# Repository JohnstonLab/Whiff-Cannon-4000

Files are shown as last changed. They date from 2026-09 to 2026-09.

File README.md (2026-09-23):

# Whiff Cannon 4000
Odor Gun tribute

♫ This is not the greatest olfactometer in the world, no. This is just a tribute ♫ [to [Burton et al, 2019](https://pubmed.ncbi.nlm.nih.gov/30657873)]. [#Tribute](https://www.youtube.com/watch?v=_lK4cX5xGiQ)
We were inspired to build this after Matt Wachowiak’s presentation at ECRO 2025. 

The logic of the olfactometer’s operation is detailed in [the original paper](https://pubmed.ncbi.nlm.nih.gov/30657873).  
This page details the following:
1) Our [Modifications](#Modifications)
2) The 3D print files for our [custom parts](#custom-parts) 
3) Off the shelf [parts list](#off-the-shelf-parts-list)
4) Jupyter notebook based **[software](#Software) to control the olfactometer**, including outputting the timing and valve that was actuated, triggering of other devices and recording of signals (e.g. PID alongside valve timings)
5) [Calibration data](#Calibrations) for our assembled device

The building and testing of this olfactometer were carried out primarily by Georgina Bonny, Adam Barrett and Shreya Choudhuri.

If you use any of this project please cite:  and [the original paper](https://pubmed.ncbi.nlm.nih.gov/30657873).

## Modifications
We have made the following adjustments:

1) Decreased diameter of carrier stream (13.87 mm inner diameter reduced to 5 mm).
2) Increased capacity of odour reservoirs (we were unable to source the original reservoirs in Europe). 

Our delivery barrel was redesigned to account for these differences as shown below.
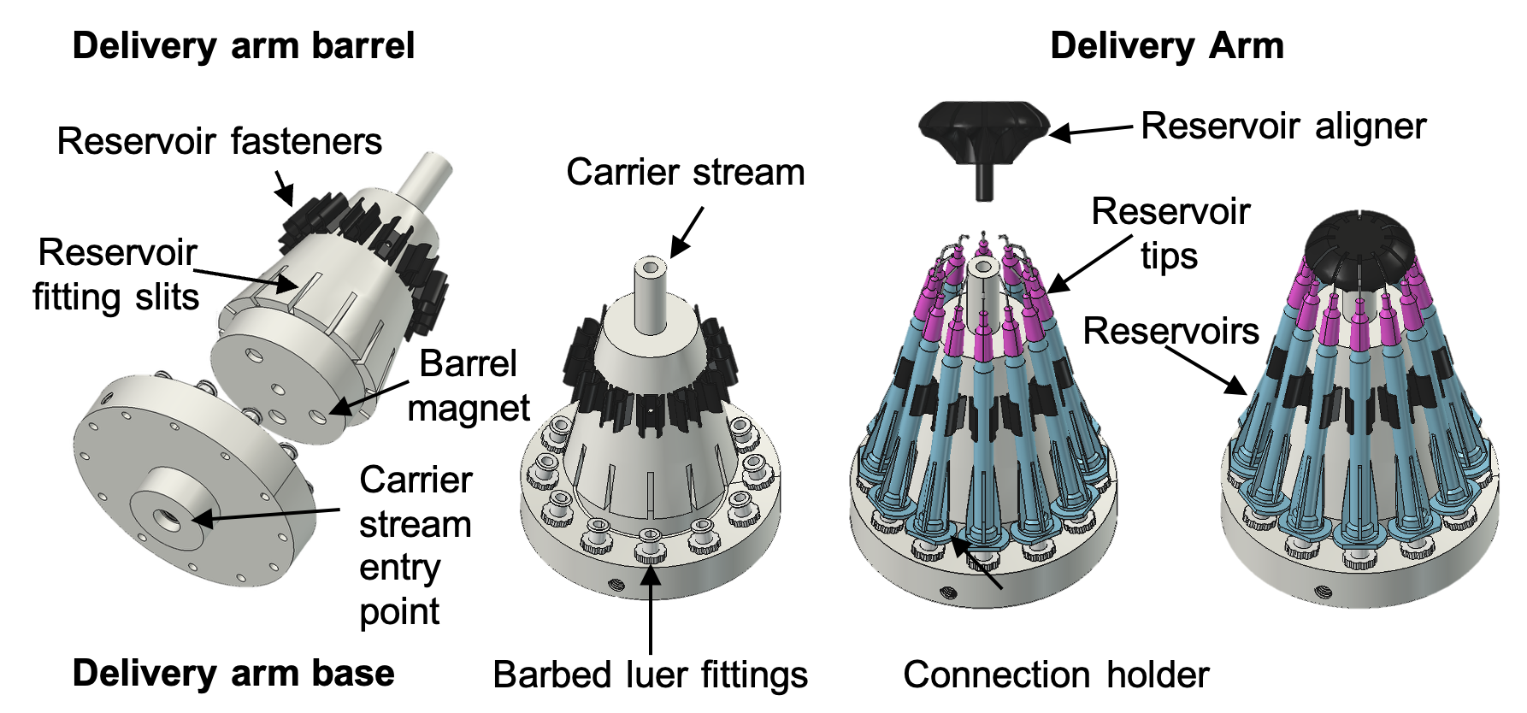
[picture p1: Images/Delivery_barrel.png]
Delivery barrel assembly

Delivery assembly IRL    
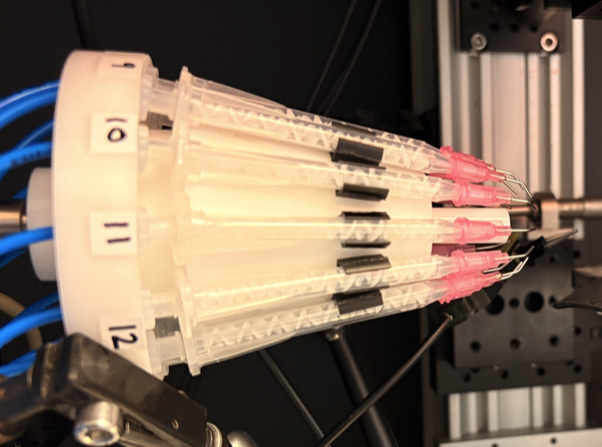
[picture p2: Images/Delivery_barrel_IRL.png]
Delivery barrel assembly IRL


The top mount can be easily and rapidly switched, enabling many 10s to over 100 odours to be delivered to a single animal. 

The enclosure housing the solenoid valves and electronics was made from a Thorlabs enclosure.	

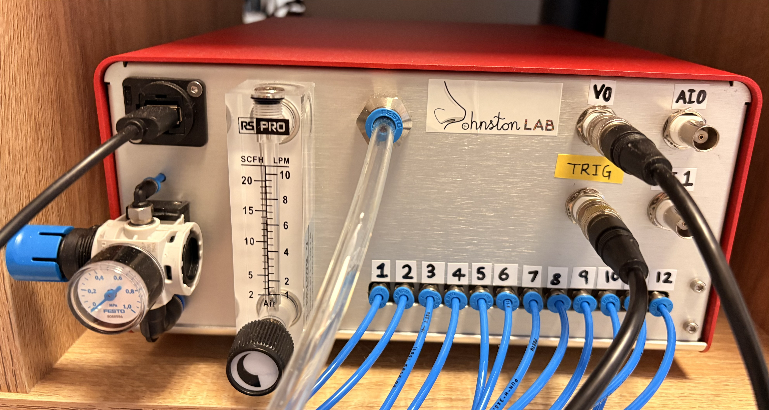
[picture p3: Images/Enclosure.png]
Enclosure

- There are 2 analog inputs (AI0 & AI1) enabling recording of PID and valve actuations
- VO gives a signal corresponding to valve and carrier stream activity
- Trig provides an output TTL for triggering other equipment

## Custom parts
[We provide 3D print files for the delivery barrel and tip aligner](https://github.com/JohnstonLab/Whiff-Cannon-4000/tree/main/Custom_parts). The tip aligner ensures the tips are aligned into the narrower carrier stream.

## Off the shelf parts list
[Parts list](off_the_shelf_components.md) for all other components and consumables that may be easier to source for interested Europeans.

## Software
The software is based on our Better Olfactometer Software(s) [BOSs repository](https://github.com/JohnstonLab/BOSs).
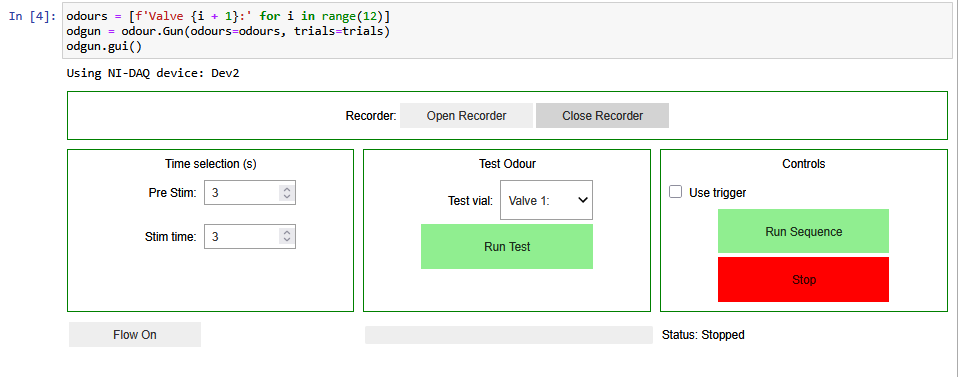
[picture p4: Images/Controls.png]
Controls

- Time setting box applies only to running a test. You can select a valve from the drop down menu and deliver a single trial by clicking 'Run Test'. 
- 'Flow on' button turns carrier stream on and sets the VO BNC port to 0.5V to indicate that flow is on
- 'Stop' button closes all valves and stops the carrier stream, can interrupt all other processes.
- 'Use trigger' checkbox will generate a TTL pulse at the start of each 'Pre (s)' period defined in a protocol sequence
- 'Run Sequence' will execute a sequence that has been loaded in the previous cell. Sequences are stored as csv files with the following structure. You can create multiple sequences and load them as necessary. The progress bar indicates place in sequence and the 'Status:' text will report the next step of the sequence.

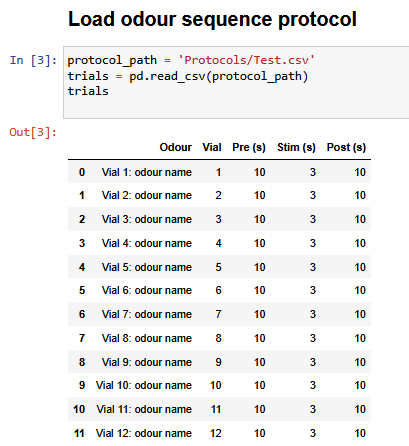
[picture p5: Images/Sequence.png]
Sequence example

- Open / close Recorder, opens a new floating window to display and record signals from AI0 & AI1. It can be used simultaneously with the control panel in the Jupyter notebook.
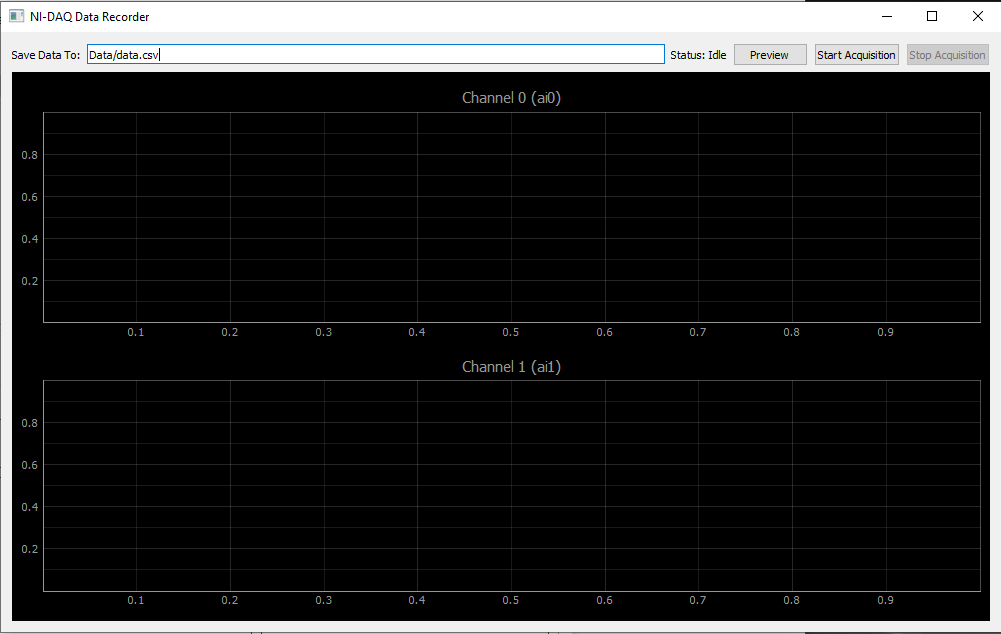
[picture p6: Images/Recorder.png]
Recorder


## Calibrations
We routinely use 0.2 MPa for the odour delivery valve pressure and 3 l min -1 for the flow rate of the carrier stream, with the whiff canon 4000 positioned 4 cm from the nose of the subject.

### Odour pressure 
Varying the odour delivery valve pressure, all measured with the carrier stream set at 3 l min-1. Measured with a miniPID 4 mm from whiff cannon 4000 tip.
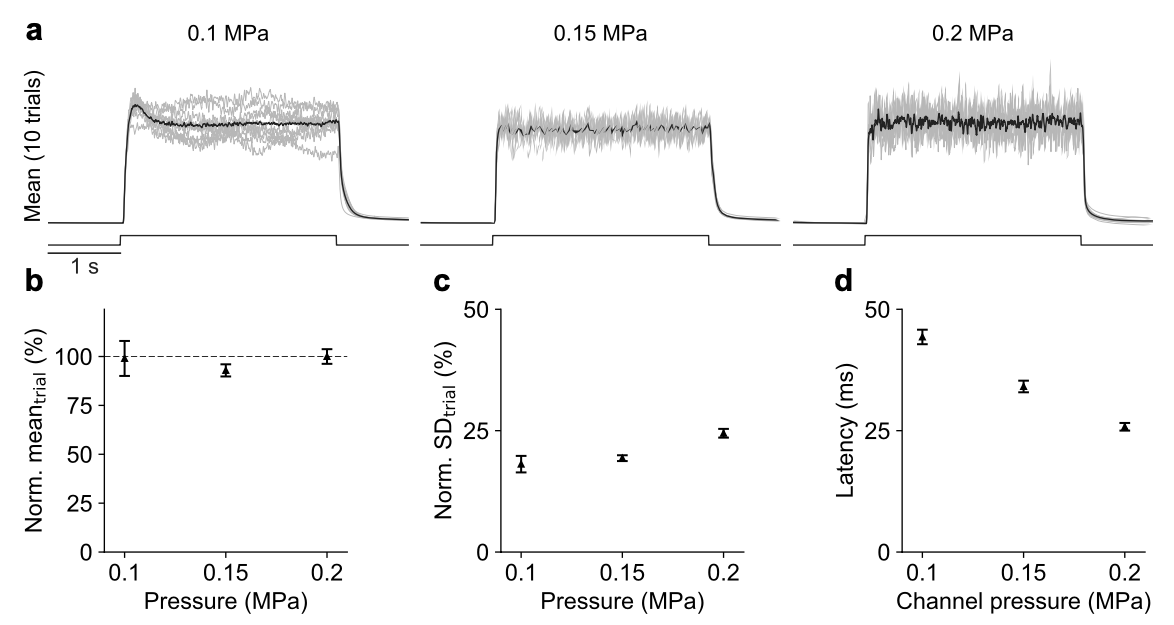
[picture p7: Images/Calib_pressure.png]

### Carrier flow
Varying flow rate of carrier stream with valve pressure held at 0.2 MPa. Measured with a miniPID 4 mm from whiff cannon 4000 tip.
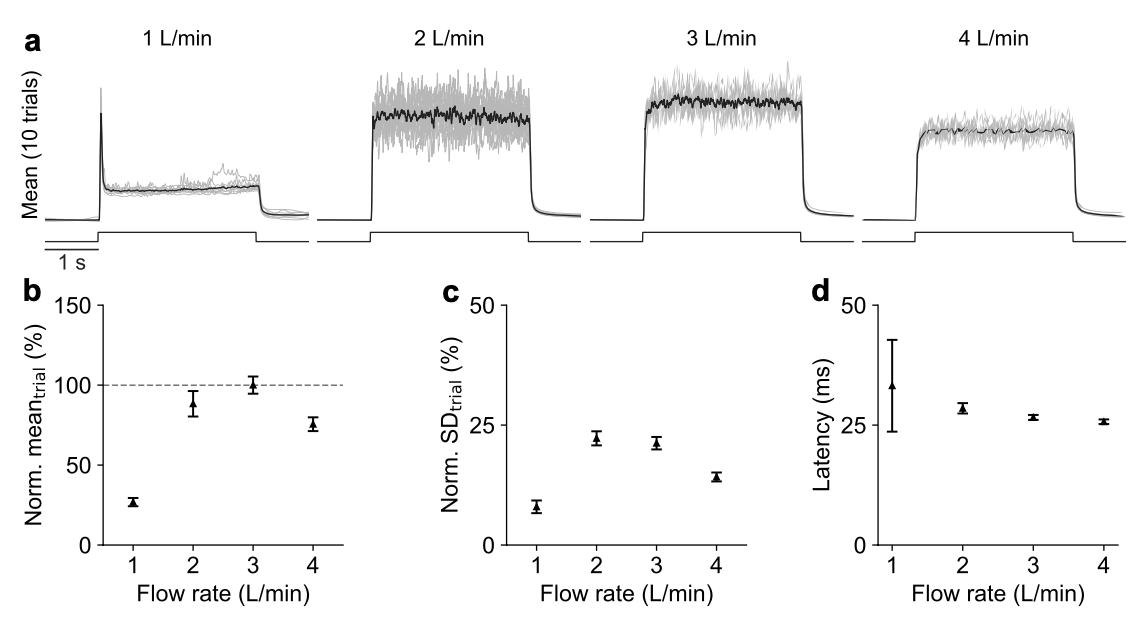
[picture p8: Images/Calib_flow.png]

### Distance 
Varying distance between whiff canon 4000 tip and test subject.
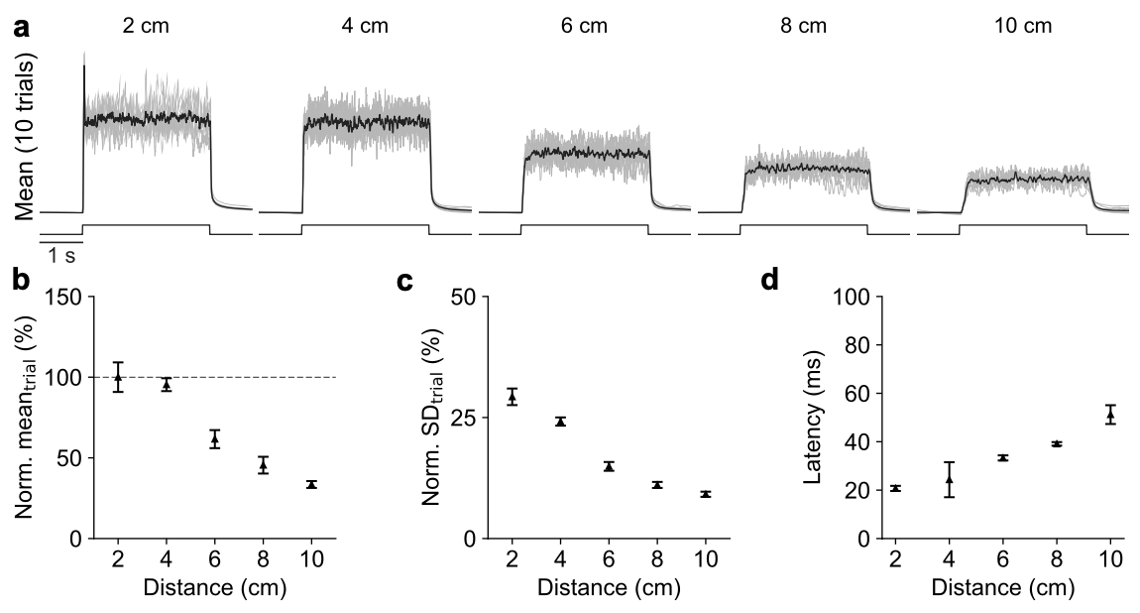
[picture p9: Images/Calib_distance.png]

### Multiple valves 
Single trial plume visualisation using TiCl4, red box indicates distance of test subject.
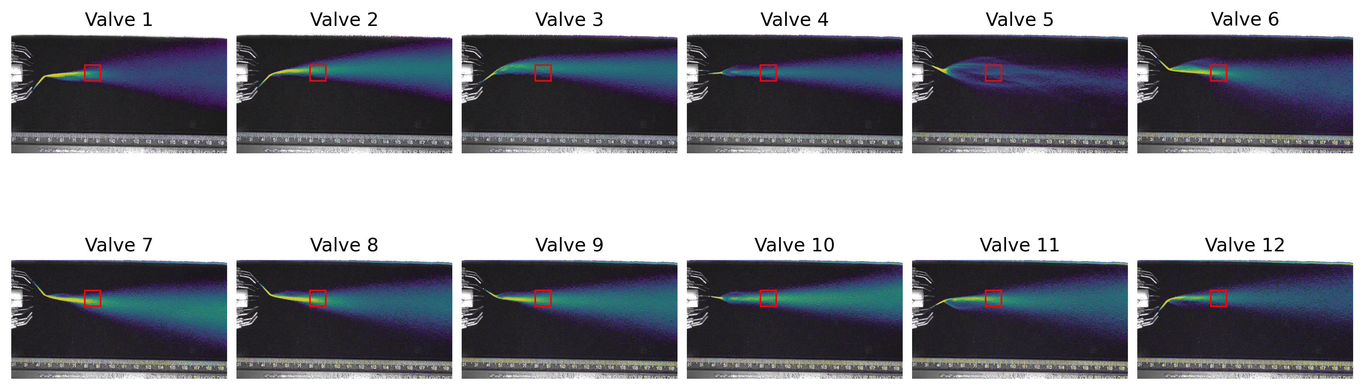
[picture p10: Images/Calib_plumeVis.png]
Plume visualisation

Mean PID recordings for each channel.
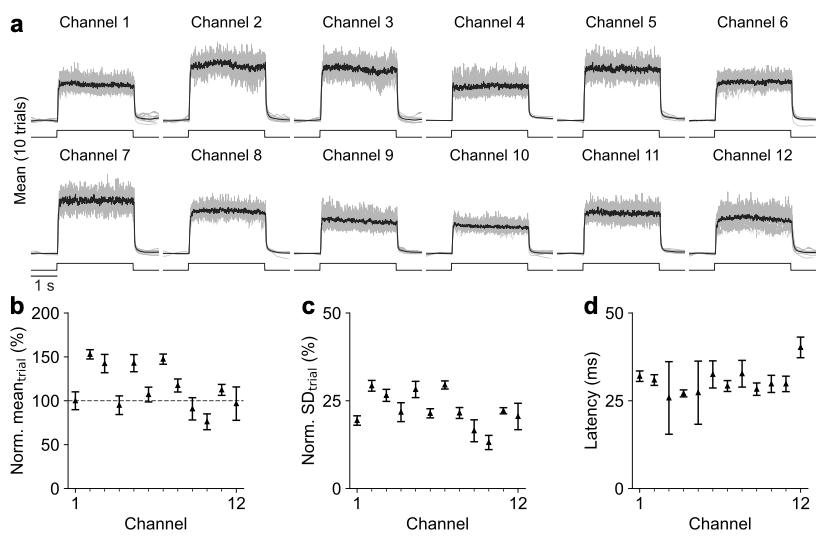
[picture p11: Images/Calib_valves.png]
PID for all channels


## Etymology
Whiff cannon 4000, why 4000? The number of preceding prototypes? Its firing position in decamicrons from the nose? Or maybe it's just there for a bit of bombastic bathos.

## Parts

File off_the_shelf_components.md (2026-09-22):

# Off-the-Shelf Components

| Olfactometer component | Part | Supplier (cat. #) |
|---|---|---|
| Flow control housing | Air flow sensor | RS Pro (257-6412) |
| | Barbed connector | SMC (M-5AN-4) |
| | Channel driver array | Microchip (MIC2981/82YN) |
| | Circuit board | Multicomp Pro (MC01009) |
| | DAQ Device | NI (USB-6001) |
| | Enclosure | Thorlabs (EC2530CR) |
| | Manifold | SMC (VV100-S41-12-M5) |
| | Pressure regulator | Festo (MS2-LR-M5-D6-AR-MPA-B) |
| | Solenoid valve | SMC (VX213AGAXB) |
| | Solenoid valve driver | SMC (V114-5LOU) |
| | 24 V power supply | RS Pro (201-2631) |
| | Tee-Connector 6mm | SMC (KQ2T06-00) |
| | Terminal Ground Bar | Sourcing map (s25050901ux2098) |
| | DIN valve connector | SMC (SY100-30-4A) |
| | BNC | Amphenol RF (B6251G2-NPP3G-50) |
| | USB A to USB A cable | RS Pro (182-8482) |
| | Chassis Mount Barrel Jack | MCM (27-4360) |
| | USB A to Micro USB B cable | RS Pro (304-18-252) |
| | Straight push in pneumatic fitting (2mm) | Festo (QSM-M5-3) |
| | Straight push in pneumatic fitting (6mm) | SMC (KQB2H06-G01) |
| | Push in bulkhead fitting (8mm) | Farnell (3431832) |
| | 6mm elbow push fitting | RS Pro (144-2613) |
| | 6mm Male push fitting | Festo (QSM-M6-6) |
| Connections | 2 mm Tubing | Festo (PEN-2X1-BL) |
| | 6 mm Tubing | Festo (PEN-6X1-BL) |
| | 8 mm Carrier flow tubing | RS Pro (917-2404) |
| Delivery arm and barrel | Aligner | Custom-machined |
| | Base | Custom-machined |
| | Eductor | Custom-machined |
| | Odorant reservoir fastener | Custom-machined |
| | Luer Fittings | Fischer Scientific (11745818) |
| Disposables | Reservoirs | Rockingham systems (100816) Static mixer RMX-5-16N |
| | 45º Bend Reservoir tips | ADL (AD72005045) |

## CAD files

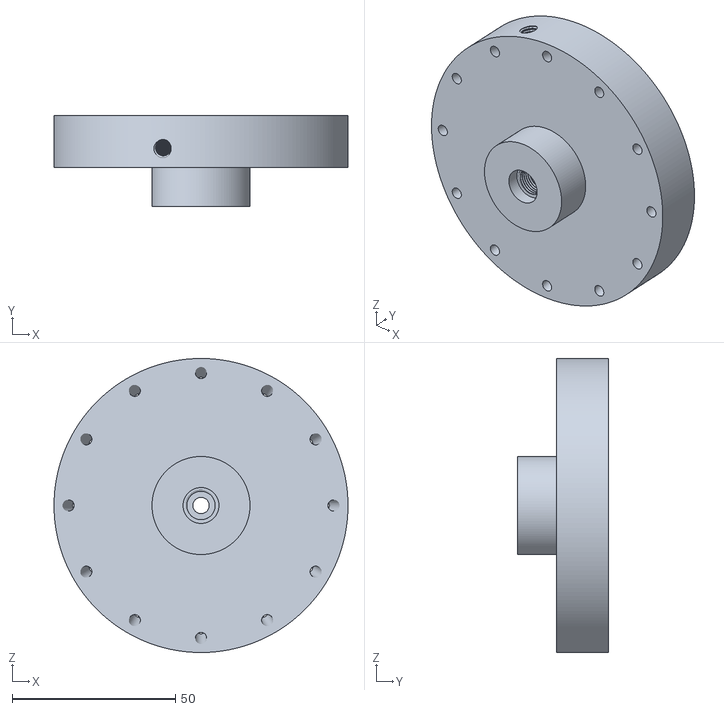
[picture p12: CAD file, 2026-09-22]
Custom_parts/Base Mount Body.stl
90.0 x 27.8 x 90.0

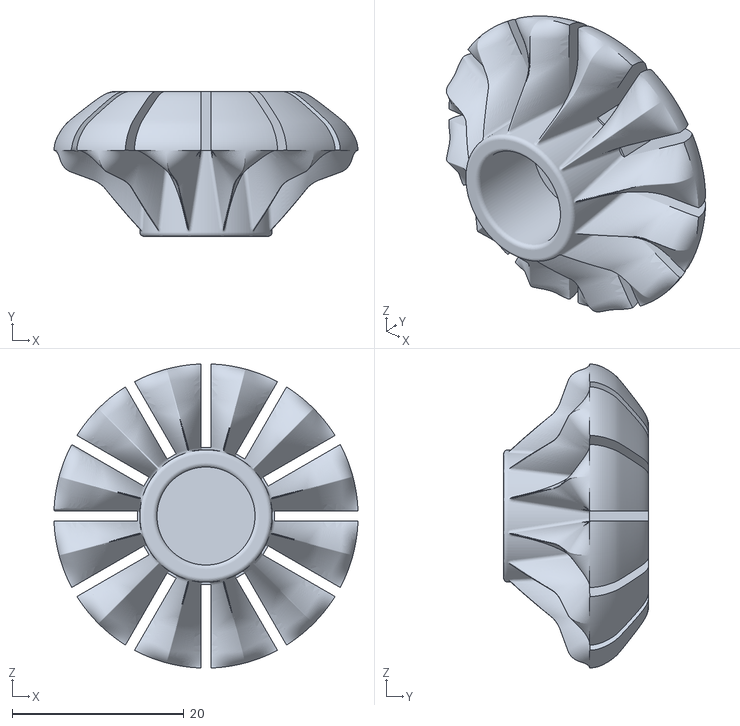
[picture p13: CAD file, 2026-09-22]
Custom_parts/Aligner V3_1.stl
35.4 x 16.9 x 35.4

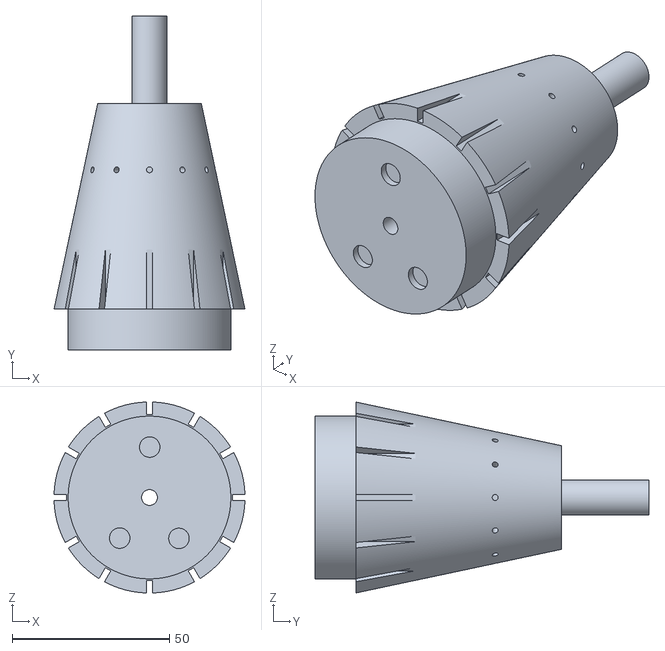
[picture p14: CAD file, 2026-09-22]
Custom_parts/Top Mount 2_0.stl
60.6 x 106.1 x 60.6

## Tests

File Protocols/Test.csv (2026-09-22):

Odour | Vial | Pre (s) | Stim (s) | Post (s)
Vial 1: odour name | 1 | 10 | 3 | 10
Vial 2: odour name | 2 | 10 | 3 | 10
Vial 3: odour name | 3 | 10 | 3 | 10
Vial 4: odour name | 4 | 10 | 3 | 10
Vial 5: odour name | 5 | 10 | 3 | 10
Vial 6: odour name | 6 | 10 | 3 | 10
Vial 7: odour name | 7 | 10 | 3 | 10
Vial 8: odour name | 8 | 10 | 3 | 10
Vial 9: odour name | 9 | 10 | 3 | 10
Vial 10: odour name | 10 | 10 | 3 | 10
Vial 11: odour name | 11 | 10 | 3 | 10
Vial 12: odour name | 12 | 10 | 3 | 10

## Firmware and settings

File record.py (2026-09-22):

# odour.py
'''
Writen by Johnston lab 2025
Designed to work with a NIDAQ-6001
Records 2 channels of analog in data at 1kHz with live display
'''
import sys, time, csv, threading
import numpy as np
import nidaqmx
from nidaqmx.constants import AcquisitionType, TerminalConfiguration # MODIFIED: Added TerminalConfiguration
from nidaqmx.system import System
from PyQt5 import QtWidgets, QtCore
import pyqtgraph as pg
import os 
import re 


class Record(QtWidgets.QWidget): # CHANGED: Class name changed from SmoothDAQViewer to Record
    acquisition_state_changed = QtCore.pyqtSignal(bool)
    acquisition_error = QtCore.pyqtSignal(str)

    """
    Continuous NI-DAQ data viewer using a ring buffer for smooth plotting and
    a separate thread for full-rate data acquisition and logging.
    """
    def __init__(self, sample_rate=1000, samples_per_read=100, window_sec=5, filename="Data/data.csv"):
        super().__init__()
        self.setWindowTitle("NI-DAQ Data Recorder") # CHANGED: Updated window title

        # --- Configuration and State ---
        self.fs = sample_rate          # Sampling rate (Hz)
        self.read_n = samples_per_read # Samples acquired per read call
        self.win_sec = window_sec      # Time window to display on plot (seconds)
        self.running = False           # Flag for acquisition thread state
        self.save_data = False         # True when actively recording to CSV
        self.reader = None             # Acquisition thread handle
        self._buffer_lock = threading.Lock()

        # --- NI-DAQ Setup ---
        # Detect the first available device (e.g., 'Dev1')
        try:
            self.dev = System.local().devices[0].name
        except IndexError:
             raise RuntimeError("No NI-DAQ device found.")
        print(f"Using NI-DAQ device: {self.dev}")

        self.task = nidaqmx.Task()
        # Add two analog input channels (ai0 and ai1)
        # MODIFIED: Added terminal_config=TerminalConfiguration.RSE to both channels
        self.task.ai_channels.add_ai_voltage_chan(
            f"{self.dev}/ai0", 
            max_val=10.0, 
            min_val=-10.0,
            terminal_config=TerminalConfiguration.RSE
        )
        self.task.ai_channels.add_ai_voltage_chan(
            f"{self.dev}/ai1", 
            max_val=10.0, 
            min_val=-10.0,
            terminal_config=TerminalConfiguration.RSE
        )

        # Configure continuous sampling timing
        self.task.timing.cfg_samp_clk_timing(
            self.fs,
            sample_mode=AcquisitionType.CONTINUOUS,
            samps_per_chan=self.read_n
        )

        # --- Ring Buffer Initialization ---
        # The buffer holds 2x the display window size for safe wrap-around handling
        self.buflen = int(self.fs * self.win_sec * 2)
        # 2 channels (rows), buffer length (columns)
        self.data = np.zeros((2, self.buflen))
        self.time = np.zeros(self.buflen)
        self.ptr = 0 # Current total samples acquired (index pointer)

        # --- UI Setup (Vertical Layout) ---
        main_layout = QtWidgets.QVBoxLayout(self)

        # Control layout (Horizontal)
        ctrl_layout = QtWidgets.QHBoxLayout()
        self.file_edit = QtWidgets.QLineEdit(filename)
        self.status_label = QtWidgets.QLabel("Status: Idle")
        self.preview_btn = QtWidgets.QPushButton("Preview")
        self.start_btn = QtWidgets.QPushButton("Start Acquisition")
        self.stop_btn = QtWidgets.QPushButton("Stop Acquisition")
        self.stop_btn.setEnabled(False)

        ctrl_layout.addWidget(QtWidgets.QLabel("Save Data To:"))
        ctrl_layout.addWidget(self.file_edit)
        ctrl_layout.addWidget(self.status_label)
        ctrl_layout.addWidget(self.preview_btn)
        ctrl_layout.addWidget(self.start_btn)
        ctrl_layout.addWidget(self.stop_btn)
        main_layout.addLayout(ctrl_layout)

        # Plot Widget
        self.plot_widget = pg.GraphicsLayoutWidget()
        main_layout.addWidget(self.plot_widget)

        # Plot 1 (Channel 0) - Top Plot
        self.p1 = self.plot_widget.addPlot(title="Channel 0 (ai0)")
        self.p1.showGrid(x=True, y=True)
        self.c1 = self.p1.plot(pen='y')

        # Move to the next row for vertical stacking (Crucial for vertical arrangement)
        self.plot_widget.nextRow()

        # Plot 2 (Channel 1) - Bottom Plot
        self.p2 = self.plot_widget.addPlot(title="Channel 1 (ai1)")
        self.p2.showGrid(x=True, y=True)
        self.c2 = self.p2.plot(pen='c')

        # --- Connections and Timer ---
        self.preview_btn.clicked.connect(self.preview)
        self.start_btn.clicked.connect(self.start)
        self.stop_btn.clicked.connect(self.stop)
        self.acquisition_state_changed.connect(self._on_acquisition_state_changed)
        self.acquisition_error.connect(self._on_acquisition_error)

        # Timer to periodically update the plot (GUI refresh rate, e.g., 20 FPS)
        self.timer = QtCore.QTimer()
        self.timer.timeout.connect(self.update_plot)
        self.timer.start(50)
        
    def _find_next_filename(self, base_filename):
        """
        Finds the next available filename by appending a zero-padded index (e.g., _000, _001, _010).
        It first strips any existing index from the filename to ensure correct sequential numbering.
        """
        # Split filename into root and extension (e.g., 'data' and '.csv')
        root, ext = os.path.splitext(base_filename)
        
        # FIX: Strip any existing _XXX index from the root name (e.g., 'data_001' -> 'data')
        # This ensures the numbering always starts from the clean base name.
        root = re.sub(r'_\d{3}$', '', root)
        
        # MODIFIED: Start the index search from 0 (for data_000.csv)
        index = 0
        while index < 1000: # Limit check to prevent indefinite loop
            # Use f-string formatting to zero-pad the index to three digits
            new_filename = f"{root}_{index:03d}{ext}"
            if not os.path.exists(new_filename):
                return new_filename
            index += 1
            
        # Fallback if 1000 indexed files already exist
        return base_filename 

    # --- Acquisition Thread Logic ---
    def acq_loop(self):
        """Runs in a separate thread to continuously read NI-DAQ data and optionally log to CSV."""
        writer_obj = None
        try:
            if self.save_data:
                # The filename is guaranteed to be unique thanks to start()
                writer_obj = open(self.file_edit.text(), "w", newline="")
                w = csv.writer(writer_obj)
                w.writerow(["Time(s)", "Ch0(V)", "Ch1(V)"])

            while self.running:
                # Read a block of samples (2 channels x self.read_n samples)
                block = np.array(self.task.read(number_of_samples_per_channel=self.read_n))

                # Reshape if only one channel was read (safety check, though 2 are configured)
                if block.ndim == 1:
                    block = block[np.newaxis, :]

                n = block.shape[1]
                # Calculate time array for the new block relative to the start of acquisition
                t = (np.arange(n) + self.ptr) / self.fs

                # --- Ring Buffer Write Logic (Wrap-around handling) ---
                with self._buffer_lock:
                    i0 = self.ptr % self.buflen # Start index in buffer
                    i1 = (i0 + n) % self.buflen # End index in buffer

                    if i1 > i0:
                        # Simple case: No wrap-around
                        self.data[:, i0:i1] = block
                        self.time[i0:i1] = t
                    else:
                        # Wrap-around case: Data splits into two segments
                        k = self.buflen - i0
                        # Segment 1: from i0 to end of buffer
                        self.data[:, i0:] = block[:, :k]
                        self.time[i0:] = t[:k]
                        # Segment 2: from start of buffer to i1
                        self.data[:, :i1] = block[:, k:]
                        self.time[:i1] = t[k:]

                    self.ptr += n # Advance the total sample pointer

                if self.save_data:
                    # Save full-rate data to CSV
                    # Using np.transpose to iterate rows efficiently
                    w.writerows(zip(t, *block))
        except Exception as e:
            print(f"Acquisition Error: {e}")
            self.acquisition_error.emit(str(e))
        finally:
            if writer_obj is not None:
                writer_obj.close()
            print("Acquisition thread ended.")
            # Ensure UI reflects stopped state if error occurred
            self.running = False
            self.save_data = False
            self.acquisition_state_changed.emit(False)

    def _start_acquisition(self, save_data):
        """Starts acquisition in either preview mode or recording mode."""
        if self.running or (self.reader is not None and self.reader.is_alive()):
            return

        self.save_data = save_data
        if self.save_data:
            # Determine the unique filename and update the QLineEdit display
            new_filename = self._find_next_filename(self.file_edit.text())
            self.file_edit.setText(new_filename)
            self.status_label.setText("Status: Recording")
            print(f"Acquisition started, saving to {self.file_edit.text()}")
        else:
            self.status_label.setText("Status: Preview")
            print("Preview started (display only, no file will be written).")

        self.running = True
        self.ptr = 0 # Reset buffer pointer on start
        self.acquisition_state_changed.emit(True)

        # Start the background data reader thread
        self.reader = threading.Thread(target=self.acq_loop, daemon=True)
        self.reader.start()

    def preview(self):
        """Starts a live preview without recording data to disk."""
        self._start_acquisition(save_data=False)

    def start(self):
        """Starts the NI-DAQ task and acquisition thread with CSV recording enabled."""
        self._start_acquisition(save_data=True)


    def stop(self):
        """Sets the flag to stop the acquisition thread."""
        if not self.running:
            return
        self.status_label.setText("Status: Stopping")
        self.running = False
        self.save_data = False
        self.stop_btn.setEnabled(False)
        # Note: The thread will finish its current read and exit the loop gracefully.


    def update_plot(self):
        """Updates the pyqtgraph plot with the latest data from the ring buffer."""
        if not self.running:
            return

        with self._buffer_lock:
            # Calculate the size of the data window to display
            nwin = int(self.fs * self.win_sec)
            end = self.ptr % self.buflen # Current end index in the buffer
            start = (end - nwin) % self.buflen # Start index for the display window

            # --- Ring Buffer Read Logic (Wrap-around handling) ---
            if start < end:
                # Simple case: Data is contiguous
                x = self.time[start:end].copy()
                y0 = self.data[0, start:end].copy()
                y1 = self.data[1, start:end].copy()
            else:
                # Wrap-around case: Concatenate the end and start segments
                x = np.concatenate((self.time[start:], self.time[:end]))
                y0 = np.concatenate((self.data[0, start:], self.data[0, :end]))
                y1 = np.concatenate((self.data[1, start:], self.data[1, :end]))

        # Decimate the data for faster plotting if there are too many points
        decim = max(1, len(x)//2000)
        x_decim = x[::decim]
        y0_decim = y0[::decim]
        y1_decim = y1[::decim]

        # Update plot data
        self.c1.setData(x_decim, y0_decim)
        self.c2.setData(x_decim, y1_decim)

        # Autoscroll the X-axis to show the latest window
        if x.size > 0:
            for p in (self.p1, self.p2):
                p.setXRange(x[-1] - self.win_sec, x[-1])

    @QtCore.pyqtSlot(bool)
    def _on_acquisition_state_changed(self, running):
        self.file_edit.setReadOnly(running)
        self.preview_btn.setEnabled(not running)
        self.start_btn.setEnabled(not running)
        self.stop_btn.setEnabled(running)
        if not running and not self.status_label.text().startswith("Status: Error"):
            self.status_label.setText("Status: Idle")

    @QtCore.pyqtSlot(str)
    def _on_acquisition_error(self, error_message):
        self.status_label.setText(f"Status: Error - {error_message}")
        QtWidgets.QMessageBox.critical(self, "Acquisition Error", error_message)


    def closeEvent(self, event):
        """
        Called when the application window is closed. Ensures the acquisition 
        thread is stopped and the NI-DAQ task is closed properly.
        """
        print("Application closing: Stopping DAQ task and thread...")
        self.stop()
        # Give the thread a moment to finish its current read and exit loop
        if self.reader is not None and self.reader.is_alive():
            self.reader.join()

        # Essential: Close the NI-DAQ task handle to release resources
        self.task.close()
        event.accept()


def main():
    """Main application entry point."""
    app = QtWidgets.QApplication(sys.argv)
    w = Record(sample_rate=1000, samples_per_read=100, window_sec=5) # CHANGED: Class instantiation
    w.resize(1000, 600)
    w.show()
    sys.exit(app.exec_())


if __name__ == "__main__":
    main()

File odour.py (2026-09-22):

# odour.py
'''
Writen by Johnston lab 2025
Designed to work with a NIDAQ-6001
Runs in jupyterlab
'''

import asyncio
import subprocess
import sys
from pathlib import Path
import numpy as np
import pandas as pd
import ipywidgets as widgets
import nidaqmx

class Gun:
    NUM_VALVES = 12
    REQUIRED_TRIAL_COLUMNS = ("Pre (s)", "Stim (s)", "Vial")
    TRIGGER_PULSE_S = 0.02

    def __init__(self, odours, trials=None):
        # -------------------------------
        # Save user data
        # -------------------------------
        self.odours = odours
        self.trials = trials
        self.running = False
        self.FLOW = 0
        self._run_task = None
        self._record_process = None
        self._record_script = Path(__file__).with_name("record.py")

        # -------------------------------
        # Detect NI-DAQ devices
        # -------------------------------
        devices = [device.name for device in nidaqmx.system.System.local().devices]
        if not devices:
            raise RuntimeError("No NI-DAQ devices detected. Please connect a device.")
        self.device_name = devices[0]
        print(f"Using NI-DAQ device: {self.device_name}")

        # -------------------------------
        # Setup digital output channels
        # -------------------------------
        self.gunValves = nidaqmx.Task()
        for i in range(8):
            self.gunValves.do_channels.add_do_chan(f"{self.device_name}/port0/line{i}")
        for i in range(4):
            self.gunValves.do_channels.add_do_chan(f"{self.device_name}/port1/line{i}")
        
        self.flowValve = nidaqmx.Task()
        self.flowValve.do_channels.add_do_chan(f"{self.device_name}/port2/line0")

        # -------------------------------
        # Setup analog output channel
        # -------------------------------
        self.gunAO = nidaqmx.Task()
        self.gunAO.ao_channels.add_ao_voltage_chan(f"{self.device_name}/ao0")

        self.triggerAO = nidaqmx.Task()
        self.triggerAO.ao_channels.add_ao_voltage_chan(f"{self.device_name}/ao1")
        self.triggerAO.write(0)

        # -------------------------------
        # GUI widgets
        # -------------------------------
        self.txSize = widgets.Layout(width='60%', height='45px')
        self.buttonSize = widgets.Layout(width='60%', height='50px')

        self.FlowOn = widgets.Button(description='Flow On')
        self.FlowOn.on_click(self.flowStart)

        self.Stopflow = widgets.Button(description='Stop', layout=self.buttonSize, style={'button_color':'red'})
        self.Stopflow.on_click(self.stop)

        self.StartRecord = widgets.Button(description='Open Recorder')
        self.StartRecord.on_click(self.start_recorder)
        self.StopRecord = widgets.Button(description='Close Recorder', style={'button_color':'lightgray'})
        self.StopRecord.on_click(self.stop_recorder)

        self.OdourList = widgets.Dropdown(options=self.odours, value=self.odours[0],
                                         description='Test vial:', disabled=False, layout=self.txSize)

        self.Run = widgets.Button(description='Run Sequence', style={'button_color':'lightgreen'}, layout=self.buttonSize)
        self.Run.on_click(self.running_seq)

        self.RunTest = widgets.Button(description='Run Test', style={'button_color':'lightgreen'}, layout=self.buttonSize)
        self.RunTest.on_click(self.running_test)

        self.StimDur = widgets.BoundedFloatText(value=3, min=0.02, max=120, description='Stim time:', layout=self.txSize)
        self.PreStim = widgets.BoundedFloatText(value=3, min=0, description='Pre Stim:', layout=self.txSize)
        self.UseTrigger = widgets.Checkbox(value=False, description='Use trigger', indent=False)

        self.prog = widgets.IntProgress(value=0, min=0, max=10, step=1, orientation='horizontal',
                                        layout=widgets.Layout(width='100%'))
        self.Status = widgets.Label(value='Status: Stopped', layout=widgets.Layout(width='100%', height='50px'))

    # -------------------------------
    # Valve control functions
    # -------------------------------
    def flow_on(self):
        d = np.ones(1)
        self.flowValve.write(d == 1)
        self.FLOW = 1
        self.gunAO.write(1)
        # print(f"Valve {v} ON, AO={(v + 1) / 2}")

    def _validate_vial_index(self, v):
        if not 0 <= int(v) < self.NUM_VALVES:
            raise ValueError(f"Valve index must be between 0 and {self.NUM_VALVES - 1}. Got: {v}")

    def _set_run_state(self, is_running):
        self.running = is_running
        self.Run.disabled = is_running
        self.RunTest.disabled = is_running

    def _validate_trials(self):
        if self.trials is None:
            raise ValueError("No trials loaded. Provide a trial DataFrame before running the sequence.")
        missing = [c for c in self.REQUIRED_TRIAL_COLUMNS if c not in self.trials.columns]
        if missing:
            raise ValueError(f"Trials missing required columns: {missing}")

        trial_df = self.trials.copy()
        if "Post (s)" not in trial_df.columns:
            trial_df["Post (s)"] = 0
            print("Protocol missing 'Post (s)' column; assuming 0 s post time.")

        for col in ("Pre (s)", "Stim (s)", "Post (s)", "Vial"):
            trial_df[col] = pd.to_numeric(trial_df[col], errors="raise")
        if (trial_df["Vial"] < 1).any() or (trial_df["Vial"] > self.NUM_VALVES).any():
            raise ValueError(f"'Vial' values must be in range 1-{self.NUM_VALVES}.")
        self.trials = trial_df

    def _start_task(self, coro, status):
        if self._run_task is not None and not self._run_task.done():
            self.Status.value = "Status: Already running. Stop current run before starting a new one."
            return

        self.Status.value = status
        self._set_run_state(True)
        try:
            # ensure_future is more tolerant in notebook event-loop contexts.
            self._run_task = asyncio.ensure_future(coro)
            self._run_task.add_done_callback(self._on_task_done)
        except Exception as exc:
            try:
                coro.close()
            except Exception:
                pass
            self._set_run_state(False)
            self._run_task = None
            self.Status.value = f"Status: Error - could not start task ({exc})"

    def _on_task_done(self, task):
        self._set_run_state(False)
        self._run_task = None
        if task.cancelled():
            return
        exc = task.exception()
        if exc is not None:
            self.Status.value = f"Status: Error - {exc}"

    def toggle_on(self, v):
        self._validate_vial_index(v)
        d = np.zeros(self.NUM_VALVES)
        d[v] = 1
        self.gunValves.write(d == 1)
        if self.FLOW == 1:
            self.gunAO.write(((v + 1) / 3)+1)
        else:
            self.gunAO.write(((v + 1) / 3))
        # print(f"Valve {v} ON, AO={(v + 1) / 2}")
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

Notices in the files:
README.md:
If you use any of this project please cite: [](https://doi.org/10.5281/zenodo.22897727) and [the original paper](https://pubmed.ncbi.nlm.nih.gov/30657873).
